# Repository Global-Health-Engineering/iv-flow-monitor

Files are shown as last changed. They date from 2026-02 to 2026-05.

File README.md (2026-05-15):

# Dripito — IV Drip Flow Monitor (Rev-B)

> Improving a low-cost intravenous infusion flow-rate monitoring device
> for paediatric care in humanitarian healthcare settings.
> ETH Zürich, Global Health Engineering — semester project, 2026.

A single-AA-cell IV drip monitor for resource-constrained clinical
environments. Custom STM32G0 PCB, optical dual-beam drop detection,
monochrome graphic LCD, piezo alarm, ASA-printed enclosure with
gear-driven broom-holder chamber clamp.

### → Full project page: **[gluflex.github.io/dripito](https://gluflex.github.io/dripito)**





Interactive dual-beam simulation, clickable PCB architecture, validation results, architecture decisions, assembly guide. This README covers only the essentials for cloning, building, and reproducing.

## At a glance

| | |
|---|---|
| **MCU** | STM32G071C8TX |
| **Hardware** | Rev-B PCB, KiCad 8.x, hand-assembled |
| **Detection** | Dual-beam optical, sphere-model volume calibration |
| **Power** | Single AA Li-ion via FFC, TPS610981 boost converter |
| **Enclosure** | ASA white FDM, sliding-gear chamber holder — Rev-B integrates the assembly for testing; full mechanical rework expected for Rev-C |
| **Validation** | 19 gravimetric-paired bench runs across 3 sessions (5 V_50 calibration + 11 position-drift + 3 raw-waveform-paired), macro-20 drip set; 7 raw-waveform captures total (4 unpaired warm-ups) |
| **BOM** | ~CHF 39, single-qty (see project page) |
| **Submission** | 2026-05-14 |

## Reproduce the analysis

One command, on a clean machine with Docker:

```bash
cd analysis/
docker compose up regenerate-figures-sample   # cold-clone test (sample data)
docker compose up regenerate-figures          # real campaign data
```

Pipeline source: [`analysis/notebooks/validation.ipynb`](analysis/notebooks/validation.ipynb).
Dependencies hash-locked in [`analysis/requirements.txt`](analysis/requirements.txt).
Protocol: [`docs/testing-and-validation.md`](docs/testing-and-validation.md).

## Build the firmware

1. Open `firmware/STM32CubeIDE/Dripito/` in STM32CubeIDE.
2. *Project → Build All*.
3. Connect ST-Link, *Run → Debug*.

Pin maps in [`firmware/README.md`](firmware/README.md).

## Hardware fabrication

PCB from `hardware/gerbers/` (JLCPCB / PCBWay).

Enclosure: STEP and STL exports in [`hardware/3dmodels/Enclosure/`](hardware/3dmodels/Enclosure/) (source CAD in Onshape). The current Rev-B enclosure is **not the final mechanical design** — it integrates the PCB + chamber holder + optics + battery into a testable assembly so the rest of the device can be validated. A full mechanical rework is expected for Rev-C. See [`docs/decisions/chamber-holder-mechanism.md`](docs/decisions/chamber-holder-mechanism.md), [`docs/decisions/sensor-arm-alignment.md`](docs/decisions/sensor-arm-alignment.md), and [`docs/enclosure-requirements.md`](docs/enclosure-requirements.md) for the rationale and Rev-C path.

## Repository layout

```
hardware/        KiCad 8.x project — schematic, PCB, libs, datasheets, gerbers, 3D models (PCB + Enclosure)
firmware/        STM32CubeIDE workspace (Dripito Rev-B)
enclosure/       Rev-B-is-not-final framing + cross-references; CAD lives in hardware/3dmodels/Enclosure/
docs/            Architecture decisions, requirements, results, limitations
data/            Raw validation CSVs, UART logs, gravimetric scale streams, geometry, edge cases
analysis/        Reproducible analysis pipeline (Docker + Jupyter) + diagnostic plotters + figures
tools/           Bench helpers (UART logging, scale logging, position-overlay rendering)
site/            GitHub Pages source (Astro)
media/           Photos, renders, demo clips
HANDOVER.md      State-of-the-prototype handover (Rev-B → Rev-C, what works / blockers / path)
CONTRIBUTING.md  Contribution guidelines (PRs paused during grading)
```

Each folder has its own `README.md`.

For the next person picking this up, start with [`HANDOVER.md`](HANDOVER.md): what works in Rev-B scope, the three blockers (position-dependence, drop-shape oscillation, tilt sensitivity), and the Rev-C optical-front-end path. [`docs/limitations.md`](docs/limitations.md) §17 is the matching architectural finding with bench evidence.

## Citation

A bachelor thesis preceded this work:

> Catarci, L. (2025). *Improving a Low-Cost Intravenous Infusion Flow-Rate Monitoring Device for Paediatric Care in Humanitarian Healthcare Settings*. ETH Zürich, Global Health Engineering. DOI: [10.5281/zenodo.16902366](https://doi.org/10.5281/zenodo.16902366).

The Rev-B work in this repository:

> Catarci, L. (2026). *Dripito — Open-Source IV Drip Flow Monitor (Rev-B)*. ETH Zürich, Global Health Engineering. DOI: [10.5281/zenodo.20199232](https://doi.org/10.5281/zenodo.20199232).

## License

- Code, firmware, docs, data: [CC BY 4.0](LICENSE-CC-BY-4.0.md)
- Hardware (KiCad project, custom symbols, most footprints): [CERN OHL 2.0 Permissive](LICENSE-CERN-OHL-2-PERMISSIVE.md)
- Three specific custom footprints: [CC BY-SA 4.0](LICENSE-CC-BY-SA-4.0.md) — see [`hardware/IV_Flow_Monitor_Footprints.pretty/README.md`](hardware/IV_Flow_Monitor_Footprints.pretty/README.md)
- CubeMX/HAL files retain `Copyright (c) STMicroelectronics` headers.

## Author and supervision

**Leandro Catarci** — MSc Mechanical Engineering, ETH Zürich. Semester project at ETH Global Health Engineering, 2026.

**Jakub Tkaczuk** — Supervisor.
**Prof. Elizabeth Tilley** — Group head, Chair of Global Health Engineering, ETH Zürich.

**Project originator:** Dr. Michelle Niescierenko — Boston Children's Hospital / Harvard Humanitarian Initiative.
**Clinical collaborator:** Dr. Janis Tupesis — University of Wisconsin / WHO Emergency Medical Teams.

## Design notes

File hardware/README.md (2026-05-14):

# hardware/

KiCad 8.x electronic design files for the Dripito monitor PCB —
schematic, board layout, project-local symbol and footprint libraries,
component datasheets, and fabrication outputs.

## Top-level files

| File | Purpose |
|---|---|
| `flow_monitor.kicad_pro` | KiCad project file |
| `flow_monitor.kicad_sch` | Schematic |
| `flow_monitor.kicad_pcb` | Board layout |
| `sym-lib-table` | Registers `lib/IV_Flow_Monitor_Symbols.kicad_sym` |
| `fp-lib-table` | Registers `IV_Flow_Monitor_Footprints.pretty/` |
| `power_analysis.md` | Power-architecture analysis notes |

## Subdirectories

| Folder | Purpose |
|---|---|
| [`lib/`](lib/) | Project-local KiCad symbol libraries |
| [`IV_Flow_Monitor_Footprints.pretty/`](IV_Flow_Monitor_Footprints.pretty/) | Project-local KiCad footprint library |
| [`datasheets/`](datasheets/) | Component datasheets (PDFs) for everything on the BOM |
| [`gerbers/`](gerbers/) | Gerber + drill + pick-and-place fabrication outputs |
| [`3dmodels/`](3dmodels/) | 3D models (component STPs + assembled-board STEP exports) |
| [`scripts/`](scripts/) | Hardware-side automation (logo-to-footprint converter) |

## Gitignored paths

`flow_monitor-backups/` (KiCad timed snapshots), `temp/` (KiCad
scratch), `_autosave-*`, `fp-info-cache`.

## Workflow

- Open and build only via the **KiCad GUI** — no CLI build is configured.
- Hand-edits to `.kicad_sch` / `.kicad_pcb` (e.g. via scripts): always
  reopen in the KiCad GUI before committing — these files are sensitive
  to structural regressions that pass a text diff.
- New / copied symbols must have the project name in their `instances`
  block, or KiCad refuses to load them. Don't use `extends` inheritance
  across hierarchical `lib_symbols` blocks — flatten unit definitions.

## Licensing

- Three custom footprints are CC BY-SA 4.0 (see
  [`../LICENSE-CC-BY-SA-4.0.md`](../LICENSE-CC-BY-SA-4.0.md)):
  `SW_HYP_1TS005F-2500-5001`,
  `USB_C_Receptacle_GCT_USB4105-xx-A_16P_TopMnt_Horizontal`,
  `X_SW_Slide_SPDT_SSK12D07VG5`.
- All other hardware design files are CERN OHL 2.0 Permissive (see
  [`../LICENSE-CERN-OHL-2-PERMISSIVE.md`](../LICENSE-CERN-OHL-2-PERMISSIVE.md)).

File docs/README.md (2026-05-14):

# docs/

Project documentation written for an outside reader. The intent is that
someone who clones this repo cold can rebuild the device, understand why
each design decision was made, and reproduce the validation results
without having access to the author's private notes.

Anything written for personal thinking lives elsewhere (PARA-style notes
outside the repo). Anything that should accompany the artefact lives here.

## Documents in this folder

| File | Purpose |
|---|---|
| [`testing-and-validation.md`](testing-and-validation.md) | Pre-registered validation protocol (EXP-0 → EXP-6). Timestamp = pre-registration evidence. |
| [`results.md`](results.md) | Bench-day results: per-run V_true vs V_LCD, V_CAL_K derivation, residuals. |
| [`limitations.md`](limitations.md) | Honest weaknesses ranked by impact on conclusions; includes §17 position-dependence finding. |
| [`enclosure-requirements.md`](enclosure-requirements.md) | Hand-off spec for follow-up theses iterating on the 3D-printed casing. Numbered REQ-x.y requirements, verification mapping, out-of-scope rationale. |
| [`decisions/`](decisions/) | Architecture Decision Records — see [`decisions/README.md`](decisions/README.md). |
| [`bench/`](bench/) | Bench-day session notes and finding logs. |

## Naming convention

- Lowercase kebab-case (`limitations.md`, not `Limitations.md` or
  `limitations_doc.md`).
- One topic per file. Cross-link with relative paths
  (`../analysis/README.md`).
- Dates in filenames only when the document is genuinely point-in-time
  (e.g. `firmware-audit-2026-04-30.md`); otherwise prefer evergreen names.

## Style

- Write for a reader who doesn't share your context. Spell out acronyms
  on first use.
- Lead with the conclusion, then the reasoning. Bury the lede only in
  the Discussion sections where building suspense serves the reader.
- Embed data tables and Mermaid diagrams inline rather than pointing at
  external files when length permits.
- Each non-trivial claim links to its evidence: a CSV under `data/`,
  a notebook cell under `analysis/`, a commit hash, a datasheet under
  `hardware/datasheets/`.

## Cross-references to other folders

- Validation data and protocol → [`testing-and-validation.md`](testing-and-validation.md) →
  [`../data/`](../data/) (raw CSVs) → [`../analysis/`](../analysis/) (notebook).
- Hardware design rationale → [`decisions/`](decisions/) →
  [`../hardware/flow_monitor.kicad_sch`](../hardware/flow_monitor.kicad_sch).
- Firmware architecture → [`../firmware/README.md`](../firmware/README.md) →
  [`../firmware/STM32CubeIDE/Dripito/Core/`](../firmware/STM32CubeIDE/Dripito/Core/).
- Enclosure fit + Rev-C path → [`enclosure-requirements.md`](enclosure-requirements.md) →
  [`../enclosure/`](../enclosure/) → CAD source in
  [`../hardware/3dmodels/Enclosure/`](../hardware/3dmodels/Enclosure/).

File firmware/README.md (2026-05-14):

# firmware/

Embedded C firmware for the Dripito Rev-B monitor. Single CubeIDE
project at `STM32CubeIDE/Dripito/`, targeting **STM32G071C8TX**.

A Rev-A predecessor (STM32G030C8TX, hardware revision A) lives in the
bachelor-thesis archive on Zenodo
([10.5281/zenodo.16902366](https://doi.org/10.5281/zenodo.16902366));
this repository ships only the active Rev-B firmware.

## Build & flash

CubeIDE GUI only — no CLI build is configured.

1. *File → Import → Existing Projects into Workspace* — point at
   `firmware/STM32CubeIDE/Dripito/`.
2. To regenerate HAL after a peripheral config change, open
   `Dripito.ioc` and click *Generate Code*. Preserve any
   `Copyright (c) STMicroelectronics` headers — they are reapplied on
   regeneration.
3. *Project → Build All*.
4. Connect ST-Link, *Run → Debug*.

## Pin map highlights

| Function | Pin |
|---|---|
| IR detector top / bottom | PA1 / PA4 (`ADC_IR_DETECTOR_TOP/BOT`) |
| LED driver top / bottom | PB3 / PB4 (`LED_CTRL_TOP/BOT`) |
| Battery sense | PB2 (`ADC_V_BAT`) |
| Buzzer PWM | PA8 (`BUZZER_CTRL`) |
| Buttons (MUTE / MODE / RES) | PB6 / PB7 / PB8 |
| UART (debug) | PA9 / PA10 |

Source of truth: `STM32CubeIDE/Dripito/Core/Inc/main.h`.

## CubeIDE pitfalls

- `.metadata/`, `.settings/`, `.cproject`, `.project`, `Debug/`,
  `Release/`, and `*.launch` are machine-specific and gitignored.
- Editing peripheral config without regenerating the `.ioc` will
  silently desync HAL init from the documented configuration.

## License

Generated CubeMX/HAL code retains its `Copyright (c) STMicroelectronics`
headers. Hand-written code in `Core/Src/` is covered by
[`../LICENSE-CC-BY-4.0.md`](../LICENSE-CC-BY-4.0.md).

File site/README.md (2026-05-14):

# Dripito — GitHub Pages site

Astro-based static site for the Dripito open-source IV drip flow monitor. Single landing page composing every section: dual-beam architecture animation, real PCB layout (extracted from the KiCad project), analysis + validation results, architecture decisions, BOM with qty=1 / qty=1000 toggle, limitations, and an assembly walkthrough.

## Local development

```bash
npm install
npm run dev          # http://localhost:4321
npm run build        # static output to dist/
npm run preview      # preview the production build locally
```

## Deploy to GitHub Pages

The [`.github/workflows/deploy-site.yml`](../.github/workflows/deploy-site.yml) workflow builds and deploys on every push to `v2`. GitHub Pages source must be set to **GitHub Actions** in the repository settings.

`astro.config.mjs` sets `site` to the canonical Pages URL and `base` to `/dripito/`.

## Source structure

```
src/
├── layouts/Base.astro            # html/head/body shell, global CSS, OG/Twitter meta
├── pages/index.astro             # landing page — composes the components
├── components/
│   ├── Nav.astro
│   ├── Hero.astro
│   ├── Problem.astro
│   ├── DualBeam.astro            # animated SVG + live readout
│   ├── PCBArchitecture.astro     # real PCB SVG from KiCad + ADR-linked hotspots
│   ├── PowerTree.astro
│   ├── StateMachine.astro
│   ├── Analysis.astro            # bench-overlay error-budget figure
│   ├── Decisions.astro           # ADR card grid
│   ├── BuildItYourself.astro     # BOM table (CSV-driven, qty toggle)
│   ├── Assembly.astro            # step-by-step build cards
│   ├── Limitations.astro         # top-N limitations surface
│   ├── OpenQuestions.astro
│   └── Footer.astro
└── styles/global.css             # design tokens + all section styles
```

## Where the PCB SVG comes from

The PCB diagram in `PCBArchitecture.astro` was generated from the live KiCad project at `hardware/flow_monitor.kicad_pcb` via the `kicad` skill. To regenerate after a layout change:

1. Run the analyser against the `.kicad_pcb` file to emit `pcb_analysis.json`.
2. Run the build script that converts the analysis into the SVG fragment.
3. Paste the SVG into `src/components/PCBArchitecture.astro`.

## BOM data source

`BuildItYourself.astro` reads [`../hardware/bom.csv`](../hardware/bom.csv) at build time and renders it as a 6-column grouped table with a qty=1 / qty=1000 pill toggle and per-group collapse. Editing the CSV is enough to update the rendered table — no component-side changes required.

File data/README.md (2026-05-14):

# data/

All measurement data — raw UART/scale CSVs, per-drop summaries, geometry
measurements, and gravimetric ground-truth — captured during the
2026-05-13 bench campaign. Everything that feeds the analysis pipeline in
`../analysis/` lives here.

## Layout

```
data/
├── raw/                                    # Bench-captured CSVs (see below)
│   ├── 2026-05-13_macro20_50mlh_*          # Morning V_50_01..05 calibration runs
│   ├── 2026-05-13_pm_position_drift/       # Afternoon mount-height re-test (see docs/limitations.md §17)
│   └── 2026-05-14_pm/                      # Trailing bench session
├── sample/                                  # Representative subset for cold-clone reproducibility
├── geometry.json                            # Beam-separation measurement (single board, n=1)
└── gravimetric_log.csv                      # Scale-derived ground truth, per run
```

## File schemas

### `raw/2026-05-13_macro20_50mlh_*` — main calibration set

One run produces up to four files. Filename pattern:

```
2026-05-13_macro20_50mlh_<NN>_board1.csv          # UART event log (RAW/DROP/CAL rows)
2026-05-13_macro20_50mlh_<NN>_board1.log          # Raw UART text capture (audit trail)
2026-05-13_macro20_50mlh_<NN>_board1_perdrop.csv  # Per-drop summary (transit + pulses + volume)
2026-05-13_macro20_50mlh_<NN>_board1_scale.csv    # Gravimetric scale stream (timestamped grams)
```

`<NN>` is the run index (`01`..`05`, plus `_test`, `_03_streaming`, and `_04_aborted` variants).

UART CSV columns:

```
abs_ms, drop_N, transit_us, pulse_top_us, pulse_bot_us,
v_cmps, d_0.1mm, V_0.1uL, state, Q_cmLph, top_raw, bot_raw
```

`_perdrop.csv` is the post-processed condensation produced by
`../analysis/scripts/load_run.py` — one row per detected drop, aligned
to the scale stream:

```
uart_idx, step_idx, t_uart_rel_ms, t_step_rel_ms, t_lag_ms,
delta_g, v_true_uL, v_est_uL, v_diff_uL
```

`_scale.csv` is the scale stream sampled at ~23 Hz:

```
t_ms, mass_g, status
```

### `raw/2026-05-13_pm_position_drift/`

Afternoon mount-height re-test that produced the §17 position-dependence
finding (`docs/limitations.md` §17). Per-run README inside the folder
documents each mount position and the K-value required to make the
LCD-summed drop volume match the gravimetric reading at that position.

### `raw/2026-05-14_pm/`

Trailing bench captures from the day after the main campaign — kept for
provenance; not used in the headline V_50 results.

### `geometry.json`

Single-board beam-separation measurement with caliper repeats. Schema:

```json
{
  "beam_separation_mm":         {"mean": 10.2, "sd": 0.3, "n_boards_measured": 1, "cad_nominal_mm": 10.0},
  "caliper_resolution_mm":      0.05,
  "positioning_uncertainty_mm": 0.5,
  "measured_by":                "digital calipers",
  "measurement_date":           "2026-05-07"
}
```

`n_boards_measured = 1` — board-to-board scatter is un-quantified for
Rev-B and named explicitly in `docs/limitations.md` §8.

### `gravimetric_log.csv`

Per-run summary table. One row per run with:

```
run_id, csv_filename, flow_rate_target_mlh, gravimetric_mass_g,
run_duration_s, drop_count_device, notes
```

`V_true_chamber = gravimetric_mass_g / drop_count_device` (computed in
the analysis notebook) is the per-run chamber-drop ground truth used by
`../analysis/notebooks/validation.ipynb`. The `notes` column records the
firmware-constants context for each run.

## Reproducibility

`sample/` exists so the analysis notebook in `../analysis/` runs
end-to-end even without access to the full dataset. The Docker pipeline
`docker compose up regenerate-figures-sample` uses `sample/` only and is
the path exercised by CI.

The complete dataset will be deposited on Zenodo under CC BY 4.0; DOI
will be added here on mint.

## FAIR principles

- **Findable** — files referenced from this README and the Pages site;
  Zenodo DOI on submission.
- **Accessible** — public GitHub repository, no authentication.
- **Interoperable** — plain CSV with documented column meanings and units;
  JSON for structured metadata.
- **Reusable** — CC BY 4.0; provenance captured in the per-run UART log
  files; per-run gravimetric reference preserved alongside the UART
  streams.

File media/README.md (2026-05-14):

# media/

Photographs, renders, and short demo clips of the Dripito monitor —
the visual material that is embedded in the top-level `README.md`,
`docs/results.md`, and `docs/enclosure.md`, plus any presentation or
publication assets.

## Contents

| File | What it is |
|---|---|
| `pcb.jpg` | Photograph of the assembled PCB |
| `schematic.jpg` | Rendered schematic snapshot |
| `3dmodel_front.jpg` | Front view of the 3D model render |
| `3dmodel_back.jpg` | Back view of the 3D model render |

## Naming convention

- Lowercase kebab-case for stable assets:
  `assembled-device-front.jpg`, `enclosure-cross-section.png`.
- For dated / iteration shots (bench photos, print attempts):
  `YYYY-MM-DD_<short-description>.jpg` — date prefix lets `ls` order
  by capture day naturally.
- Renders include `_render` in the filename so they don't get confused
  with photographs (e.g. `assembled-device-front_render.png`).

## Format and resolution

- Photographs: JPEG, max edge ≤ 2048 px, ~80 % quality. Embed at the
  display size you actually need; do not commit 24 MP originals.
- Renders: PNG when transparency or sharp edges matter (UI mockups,
  schematic renders), JPEG otherwise.
- Animated demos: MP4 (H.264) preferred over GIF for file-size
  reasons. ≤ 5 MB per clip; longer demos go on Zenodo / YouTube and
  are linked from the README.

## What does not belong here

- Slide decks (`.pptx`, `.key`) — those go in
  `../docs/presentations/` if added.
- Photos containing identifiable patient information or clinical
  imagery without consent. None expected.
- Working files (Photoshop `.psd`, source video projects). Commit only
  the exported asset.
- Internal print-history photos for enclosure iterations — drop them next to the matching enclosure ADR / log entry rather than here.

## Embedding from Markdown

From the top-level README (or any sibling-of-`media/` markdown file), reference assets under `media/<filename>`. From a sibling folder (e.g. `docs/`), step up first: `../media/<filename>`. Concrete examples in [`../README.md`](../README.md) and [`../enclosure/README.md`](../enclosure/README.md).

Use relative paths so embedding works on GitHub, locally, and in the
GitHub Pages site.

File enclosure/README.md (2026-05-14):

# enclosure/

> **Current Rev-B enclosure is not the final mechanical design.** A full rework is expected for Rev-C. The Rev-B enclosure exists to integrate the PCB + chamber holder + optics + battery into a single testable assembly so the rest of the device (electronics, firmware, validation campaign) could be exercised. Documented honestly here; planned Rev-C path captured in the cross-referenced ADRs below.

## Where the CAD lives

- **Source CAD:** Onshape document `Dripito Rev-B`. Edits happen there.
- **Versioned exports (STEP + STL):** [`../hardware/3dmodels/Enclosure/`](../hardware/3dmodels/Enclosure/). Populated as the source CAD is exported. The exporter is manual — there is no automation; regenerate after meaningful CAD changes.

This folder (`enclosure/`) carries the rationale, requirements spec, and printing guidance. The geometry itself lives next to the PCB models in `hardware/3dmodels/Enclosure/`.

## Material

ASA white (Acrylonitrile Styrene Acrylate). Decision rationale: [`../docs/decisions/enclosure-material.md`](../docs/decisions/enclosure-material.md). Brief: ASA chosen over PETG (lower UV resistance) and ABS (higher warping risk) for outdoor humanitarian deployment contexts. White colouring reduces solar heat absorption.

## Fastener mechanism

Snap-fit assembly. No heat-set inserts, no threaded fasteners. The trade-off is that snap-fit reliability depends on print tolerance, and disassembly for service requires either flexing the snap-fit lugs or accepting that the enclosure is functionally non-serviceable. See [`../docs/decisions/enclosure-material.md`](../docs/decisions/enclosure-material.md) for the alternative path (M2 brass heat-set inserts + button-head screws) that was rejected for Rev-B.

## Print profile defaults

- Layer height: 0.2 mm (sensor arm: 0.15 mm at optical faces)
- Wall count: 4
- Top/bottom layers: 5
- Infill: 30 % gyroid
- Print orientation: sensor arm prints with the optical bore axis vertical so the LED / PD bores form circular cross sections rather than stair-stepped ellipses
- Support: tree, only where required

ASA process settings (varies by spool): enclosed chamber, ~100 °C bed, ~250 °C nozzle. Calibrate the printer before running the parts.

## Button stack-up

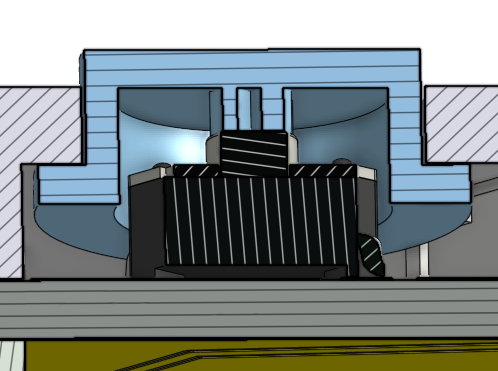
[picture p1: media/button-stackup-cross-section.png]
Button cross-section


Cross-section through a front-plate button. From bottom to top:

- **PCB** (yellow strip)
- **Tactile switch** (PTS647 series, centre — ribbed black SMD body)
- **Front-plate housing** (cross-hatched) with a chamfered bore that captures the cap
- **Button cap** (blue) with a chamfered guide that limits lateral travel

The cap presses the tactile switch directly through the housing bore. No separate light pipe or actuator pin — travel is bounded by the housing chamfer above and the switch dome below.

## Chamber-OD compatibility

Designed for ISO 8536-4-compliant drip chambers, **14–24 mm outer diameter** (microdrip + standard adult macrodrip). Validated against a Ø20 mm reference chamber.

Wide-body / transfusion chambers (25–30 mm) are **out of scope** for Rev-B. Addressable in a future revision via an interchangeable cradle insert reusing the same optical-bay interface. See [`../docs/enclosure-requirements.md`](../docs/enclosure-requirements.md) for the full spec.

## Known limitations of the Rev-B enclosure

The current Rev-B build has known mechanical compromises that were accepted to unblock the validation campaign. These are surfaced in the architecture decision records and in `docs/limitations.md`:

- **Chamber holder geometry** — sliding gear with IR-beam pass-through forces a wide beam-to-sensor distance; partly responsible for the position-dependence finding in [`../docs/limitations.md`](../docs/limitations.md) §Position-dependence. See [`../docs/decisions/chamber-holder-mechanism.md`](../docs/decisions/chamber-holder-mechanism.md).
- **Sensor-arm alignment is FDM-tolerance-bound (±0.2 mm).** Rev-C path is injection moulding (±0.05 mm). See [`../docs/decisions/sensor-arm-alignment.md`](../docs/decisions/sensor-arm-alignment.md).
- **External AA battery holder** acts as counterbalance but increases horizontal footprint, which may interfere with adjacent IV lines in a crowded clinical bay. See [`../docs/decisions/enclosure-geometry.md`](../docs/decisions/enclosure-geometry.md).
- **IP54 ingress protection is an aspiration**, not validated against IEC 60529 in Rev-B. See [`../docs/decisions/enclosure-material.md`](../docs/decisions/enclosure-material.md) §Outlook.

## Cross-references

- Requirements spec for Rev-C / follow-up: [`../docs/enclosure-requirements.md`](../docs/enclosure-requirements.md)
- ADRs governing the enclosure decisions: [`../docs/decisions/enclosure-material.md`](../docs/decisions/enclosure-material.md), [`../docs/decisions/enclosure-geometry.md`](../docs/decisions/enclosure-geometry.md), [`../docs/decisions/chamber-holder-mechanism.md`](../docs/decisions/chamber-holder-mechanism.md), [`../docs/decisions/sensor-arm-alignment.md`](../docs/decisions/sensor-arm-alignment.md)
- Geometry measurement protocol (EXP-1): [`../docs/testing-and-validation.md`](../docs/testing-and-validation.md)
- Geometry data per board: [`../data/geometry.json`](../data/README.md)

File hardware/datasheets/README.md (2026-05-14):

# hardware/datasheets/

PDF datasheets for every component on the Dripito BOM, plus selected
controller datasheets and application notes referenced from the design.

## Naming convention

- `<MPN>_datasheet.pdf` for the primary datasheet of a component
  (`STM32G030C8_datasheet.pdf`, `AO3401A_datasheet.pdf`).
- `<part_or_topic>_<descriptor>.pdf` for application notes, controller
  datasheets, or wiring diagrams (`SSD1803A_controller_datasheet.pdf`,
  `DOG_3V3_wiring.pdf`).

## What's currently here

| File | What it is |
|---|---|
| `STM32G030C8_datasheet.pdf` | Rev-A MCU (kept for reference; Rev-B uses STM32G071C8 — datasheet not duplicated here, see [ST product page](https://www.st.com/en/microcontrollers-microprocessors/stm32g071c8.html)) |
| `TPS610981_datasheet.pdf` | TPS61098-family boost converter — Rev-B uses the TPS610981 variant per the schematic (see [`../../docs/decisions/power-architecture.md`](../../docs/decisions/power-architecture.md)). The PDF is the joint datasheet for the TPS61098, TPS610981, and TPS610982 voltage variants. |
| `AO3401A_datasheet.pdf` | P-channel MOSFET |
| `EA_DOGS164W-A_datasheet.pdf` + `_extended_datasheet.pdf` | LCD module (4×16) |
| `DOG_3V3_wiring.pdf` | LCD wiring reference |
| `SSD1803A_controller_datasheet.pdf` | LCD controller IC; required for the BF-read protocol |
| `PTS647_datasheet.pdf` | Tactile switches (S1 / S2 / S3 buttons) |
| `competitors/` | Reference material for prior-art devices (DripAssist) |

## What does **not** belong here

- Product brochures and marketing PDFs that aren't actual technical references.
- Datasheets for components considered but rejected — those belong in
  the relevant decision record, not here.

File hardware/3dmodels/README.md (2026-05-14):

# hardware/3dmodels/

3D models for component visualisation in the KiCad PCB editor, the
exported board `.step`, and the mechanical enclosure exports. Organised
into subfolders by what each model represents.

## Layout

```
hardware/3dmodels/
├── PCB/              # Board + on-PCB component models
│   ├── PTS647SN38SMTR2_LFS.stp
│   ├── flow_monitor.step
│   └── flow_monitor_full.step
└── Enclosure/        # Mechanical enclosure exports from Onshape (STEP + STL)
                      # (populated as the source CAD is exported)
```

## PCB models

| File | What it is |
|---|---|
| `PCB/PTS647SN38SMTR2_LFS.stp` | 3D model for the PTS647 tactile switch |
| `PCB/flow_monitor.step` | Assembled-board STEP export from KiCad (board only) |
| `PCB/flow_monitor_full.step` | Assembled-board STEP export including 3D component models |

Conventions for PCB models:

- One file per component, named after the part's MPN: `<MPN>.stp` or `<MPN>.wrl`.
- STEP (`.stp` / `.step`) preferred over VRML (`.wrl`) — STEP preserves geometry for the assembled board export.
- Models come from manufacturer or distributor websites (DigiKey / Mouser / vendor 3D-model download links). Note provenance in the BOM entry.

## Enclosure models

Source CAD lives in Onshape (`Dripito Rev-B`). STEP and STL exports land in `Enclosure/` for version-controlled distribution to slicers and downstream consumers.

The current Rev-B enclosure is **not the final mechanical design**. It exists to integrate the PCB + chamber holder + optics + battery into a testable assembly so the rest of the device can be validated. A full rework is expected for Rev-C — see [`../../docs/decisions/chamber-holder-mechanism.md`](../../docs/decisions/chamber-holder-mechanism.md), [`../../docs/decisions/sensor-arm-alignment.md`](../../docs/decisions/sensor-arm-alignment.md), and [`../../docs/decisions/enclosure-material.md`](../../docs/decisions/enclosure-material.md) for the rationale and Rev-C path.

## Stray folders

`Neuer Ordner/` is a third-party download artefact, gitignored — not part of this project.

## License caveat

Manufacturer 3D models often carry redistribution restrictions. Most explicitly permit inclusion in derivative PCB designs and assembled mechanical models, but not standalone redistribution. If you are republishing this repo separately, audit each `.stp` against its source license terms. For models with unclear licensing, replace them with a generic shape or omit and accept the cosmetic loss in the `.step` export.

## Linking from a footprint

In the KiCad Footprint Editor:

1. *Properties → 3D Models → Add*.
2. Use a relative path: `${KIPRJMOD}/3dmodels/PCB/<MPN>.stp` so the link travels with the project.
3. Save the footprint. The board's `.step` export now picks up the model automatically.

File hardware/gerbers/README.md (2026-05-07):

# hardware/gerbers/

Fabrication outputs for the Dripito Rev-B PCB: Gerber files (one per
copper / mask / silk / paste / outline layer), drill files (PTH and
NPTH), pick-and-place files, the bundled `.zip` for fab-house upload,
and the `.gbrjob` job description.

These files are **regenerated** from `../flow_monitor.kicad_pcb` — the
`.kicad_pcb` is the source of truth. Treat the Gerbers as build
artefacts that happen to be committed for traceability.

## What's here

| File | Layer / role |
|---|---|
| `flow_monitor-F_Cu.gtl` / `-B_Cu.gbl` | Front / back copper |
| `flow_monitor-F_Mask.gts` / `-B_Mask.gbs` | Front / back solder mask |
| `flow_monitor-F_Silkscreen.gto` / `-B_Silkscreen.gbo` | Front / back silkscreen |
| `flow_monitor-F_Paste.gtp` / `-B_Paste.gbp` | Front / back paste mask |
| `flow_monitor-Edge_Cuts.gm1` | Board outline |
| `flow_monitor-PTH.drl` / `-NPTH.drl` | Plated / non-plated drill |
| `flow_monitor-top.pos` / `-bottom.pos` | Pick-and-place coordinates |
| `flow_monitor-job.gbrjob` | Job description (Gerber X3) |
| `flow_monitor.csv` | Component-position CSV (assembly) |
| `flow_monitor_gerbers.zip` | Bundled archive for fab-house upload |
| `placement/` | Auxiliary pick-and-place outputs |

## Re-exporting

After a layout change, regenerate via KiCad → *File → Fabrication
Outputs* (Gerbers, Drill Files, Component Placement). Re-zip
`flow_monitor_gerbers.zip` from the freshly generated files. Commit
with a message that names the source PCB commit:
`refactor(hardware): regenerate gerbers after <change>`.

## Fab-house

Default target: JLCPCB. 2-layer, 1.6 mm, ENIG or HASL. The same
Gerber + drill bundle works for PCBWay; pick-and-place CSV format may
need a per-fab conversion.

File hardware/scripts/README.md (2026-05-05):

# hardware/scripts/

Hardware-side automation. Currently a single script for converting
PNG / JPG logos into KiCad silkscreen footprints, plus the source
artwork it consumes.

## Contents

| File | Purpose |
|---|---|
| `logo_to_footprint.py` | Rasterises a logo image into a KiCad `.kicad_mod` footprint on F.SilkS, using `fp_poly` rectangles. Enforces the ≥ 0.2 mm minimum feature size required by JLCPCB silkscreen. Uses PIL + numpy. |
| `eth_logo.png` | ETH Zürich logo source artwork |
| `ghe_logo.jpg` | Global Health Engineering logo source artwork |

## Usage

```bash
cd hardware/scripts
python logo_to_footprint.py --input eth_logo.png \
                            --output ../IV_Flow_Monitor_Footprints.pretty/ETH_Zurich_Logo.kicad_mod \
                            --pixel-size 0.2
```

(Exact CLI may vary — read the script for the argument set it
actually accepts.)

The output footprints live in `../IV_Flow_Monitor_Footprints.pretty/`.
Regenerate them rather than hand-editing if the source artwork
changes; the script enforces silkscreen design rules so manual
editing risks producing non-fab-able geometry.

## Conventions

- Python 3 with `pillow` (PIL) and `numpy` as the only non-stdlib
  dependencies. Keep this folder dependency-light — install via system
  Python or a one-off venv; do not introduce a `requirements.txt` here
  (the analysis pipeline's pinning lives at `../../analysis/` instead).
- One script per task. If a second tool is added (e.g. a BOM diff
  helper), it gets its own file rather than expanding `logo_to_footprint.py`.
- Output destinations are passed as CLI arguments, not hard-coded —
  each script must run cleanly from the repo root or from inside this
  folder.

## What does not belong here

- Firmware build / flash scripts (those would go under
  `../../firmware/scripts/` if added).
- Analysis-pipeline code (lives at `../../analysis/scripts/`).
- Bytecode / `__pycache__/` (gitignored).

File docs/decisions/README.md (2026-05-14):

# docs/decisions/ — Architecture Decision Records

One file per significant architectural or engineering decision. The point
is that a reader can reconstruct *why* the design looks the way it does
without asking the author. Each decision page is a contract with the
future: what was decided, what alternatives were rejected, what would
trigger a revisit.

## File format

Each decision is a single Markdown file with a stable structure:

```markdown
# <Decision title>

**Date:** YYYY-MM-DD

## Context
What problem does this solve? What constraints apply? What did we know
that the reader doesn't?

## Decision
The chosen option, stated unambiguously. One sentence if possible.

## Alternatives considered
Each alternative + why it lost. Cost, risk, complexity, supplier
availability — be concrete.

## Consequences
What this decision unlocks. What it forecloses. What we now have to live
with that we didn't before.

## Revisit triggers
Conditions under which this decision should be re-opened (e.g.
"if Rev-C uses a Li-ion cell, revisit boost converter selection").
```

## Naming convention

- Lowercase kebab-case, action-or-noun phrase: `comparator-simplification.md`,
  `power-architecture.md`, `auto-calibration-at-boot.md`.
- No dates in filename (the date is inside the file, in the frontmatter
  block above). Files are evergreen even after they're superseded.
- A superseded decision **stays in the repo** with `Status: superseded by
  [link]`. Deleting it loses the reasoning trail.

## Decision records in this folder

| File | Topic |
|---|---|
| [`comparator-simplification.md`](comparator-simplification.md) | COMP1 → internal-comparator simplification (remove LMV331) |
| [`optical-architecture.md`](optical-architecture.md) | Dual-beam Phase 1 / LPTIM Phase 2 trade-off |
| [`power-architecture.md`](power-architecture.md) | Single Li-ion AA via TPS610981 boost |
| [`power-architecture-process.md`](power-architecture-process.md) | Companion record: how the power decision was made (supervisor pushback, Tupesis consultation, solar feasibility) |
| [`enclosure-material.md`](enclosure-material.md) | ASA white, FDM, snap-fit |
| [`enclosure-geometry.md`](enclosure-geometry.md) | External AA holder on sensor arm as counterbalance |
| [`sensor-arm-alignment.md`](sensor-arm-alignment.md) | FDM in Rev-B; injection moulding pathway for Rev-C |
| [`chamber-holder-mechanism.md`](chamber-holder-mechanism.md) | Sliding gear with IR-beam pass-through (Rev-C rework expected) |
| [`usb-interface-removal.md`](usb-interface-removal.md) | USB-C dropped; 5-pin UART debug header instead |
| [`battery-cell-size.md`](battery-cell-size.md) | AA retained vs AAA (DripAssist battery-life benchmark) |
| [`care-package-deployment.md`](care-package-deployment.md) | Planned deployment kit (3–5 units + alkaline AA fallback + external USB solar panel); not executed in Rev-B |
| [`battery-indicator.md`](battery-indicator.md) | Low-battery symbol via threshold (deferred to Rev-C) |
| [`led-duty-cycle.md`](led-duty-cycle.md) | Phase 2 IR LED at 0.3 % duty cycle |
| [`auto-calibration-at-boot.md`](auto-calibration-at-boot.md) | Threshold auto-calibration (primary, no fallback) |
| [`onshape-mcp-evaluation.md`](onshape-mcp-evaluation.md) | Parametric CAD tooling — evaluated, deferred to Rev-C |
| [`firmware-build-and-test-rev-c.md`](firmware-build-and-test-rev-c.md) | CubeIDE-only Rev-B firmware build; Dockerized build + host-side state-machine tests deferred to Rev-C |

## Why ADRs

A code review or supervisor reading the repo cold cannot see the
discussions, dead ends, and stakeholder pushback that shaped the design.
The ADR format makes that history explicit and durable. It captures
tacit engineering judgement as documented rationale a future
contributor or reviewer can audit.

Reference: Michael Nygard, "Documenting Architecture Decisions" (2011),
the canonical ADR pattern.

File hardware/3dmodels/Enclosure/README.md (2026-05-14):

# hardware/3dmodels/Enclosure/

Rev-B enclosure exports from the Onshape `Dripito Rev-B` assembly. The folder splits into the
printable subset (`STL/`) and the full parametric source (`STEP/`).

> The current Rev-B enclosure is **not the final mechanical design** —
> see [`../../../enclosure/README.md`](../../../enclosure/README.md) and
> [`../../../docs/decisions/chamber-holder-mechanism.md`](../../../docs/decisions/chamber-holder-mechanism.md).
> A full mechanical rework is expected for Rev-C.

## Layout

```
Enclosure/
├── STEP/   # Full Onshape assembly — 3 printable parts + 5 component reference models
└── STL/    # Rev-B printable subset — 3 parts only (slicer-ready meshes)
```

The STEPs are the authoritative geometry source from Onshape and include the full assembly
(printable parts plus reference geometry for off-the-shelf components used for clearance and
fit checks). The STLs in `STL/` are the printable subset actually fed into the slicer for the
Rev-B build.

## Printable parts (in `STL/` and `STEP/`)

| File | What it is |
|---|---|
| `Front_Case` | Front-plate housing — LCD window, button cutouts, LED bezel holes |
| `Back_Casing` | Rear shell of the device body |
| `Gear` | Sliding-gear chamber holder with the IR-beam pass-through hole (see [`../../../docs/decisions/chamber-holder-mechanism.md`](../../../docs/decisions/chamber-holder-mechanism.md)) |

All three print in ASA white per [`../../../docs/decisions/enclosure-material.md`](../../../docs/decisions/enclosure-material.md). Print profile defaults: 0.2 mm layer (sensor-arm optical faces at 0.15 mm), 4-perimeter walls, 30 % gyroid infill, tree supports where required.

## Component reference models (in `STEP/` only — not printed)

| File | What it is |
|---|---|
| `AA_Battery` | AA Li-ion cell — clearance / fit reference |
| `body`, `lock`, `pins` | FFC connector sub-bodies (housing, actuator, contact pins) — clearance reference for the on-PCB FFC connector |
| `slide_switch` | SK-12D07-G slide switch — off-board mode/power switch reference |

These remain in `STEP/` for assembly-level fit-checks. They are deliberately omitted from
`STL/` because they are off-the-shelf components, not printable.

## Source

Onshape document `Dripito Rev-B`. The exporter is manual — regenerate STEPs from Onshape after
meaningful CAD changes; export only the printable subset to `STL/`.

## Printing

For a one-shot Rev-B prototype, feed the three STLs in `STL/` (`Front_Case`, `Back_Casing`,
`Gear`) into a slicer (PrusaSlicer / OrcaSlicer / Bambu Studio) configured for ASA per the
print profile defaults above.

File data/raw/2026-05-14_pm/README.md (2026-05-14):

# 2026-05-14 PM — raw beam waveform capture across mount positions

First Dripito bench session to capture the **raw photodiode waveforms** (not just edge-time pulse durations) across mount positions where K-fit broke yesterday. The new dimension this dataset adds is shape information — rise/fall asymmetry, multi-peak structure, area-under-attenuation, umbilical/splash signatures — that the threshold-time analysis used through 2026-05-13 cannot access. Captures support the Phase 2 offline algorithm exploration in `analysis/scripts/algo_replay.py`, `analysis/scripts/algo_breadth_pass.py`, and `analysis/scripts/fit_final_algorithm.py`.

Firmware: `feat/raw-capture-rev-c` (branched from `v2`, not merged into Rev-B submission firmware — submission firmware = `v2` HEAD). Adds compile-time `ENABLE_RAW_CAPTURE=1`, sample-time `ADC_SAMPLETIME_160CYCLES_5` (160.5 cycles; an earlier 3.5-cycle attempt was reverted when the photodiode TIA didn't settle and runtime reads dropped ~10 % below boot-cal), polled register-level pair-read, 8 kB ring buffer (1024 × 8 B), 921600 baud UART (the 2 Mbps plan was reverted with the buffer halving), per-drop CSV dump on accept.

UART format addition (the rest of the schema is unchanged from `docs/results.md` references):

```
DROP_RAW_BEGIN,<t_ms>,<drop_N>,<sample_count>,<t_first_us>,<t_last_us>,<t_trigger_us>
RAW,<t_us>,<top_adc>,<bot_adc>        × sample_count rows
DROP_RAW_END,<drop_N>
```

`t_us` is the free-running TIM2 µs counter (1 MHz, 32-bit wrap-safe). `t_trigger_us` is the t_us at the TOP-entry (tT_in) edge.

## Captures

All captures at the same drip set (macro 20 gtt/mL), water, board 1, flow ≈ 50 mL/h via roller-clamp setting. Position is measured relative to the V_50_05-era canonical mount (the same mount used during the morning calibration campaign).

| Tag | Position | Has scale.csv | Role |
|---|---|---|---|
| `p1_high_capture.log` | canonical V_50_05-era| no | First-light raw-byte capture (pre-format)  |
| `p1_high_first_capture.uart.log` | canonical | no | Initial UART format-validation probe |
| `p1_high_run01.uart.log` | canonical | no | Warm-up run |
| `p1_high_run02.uart.log` | canonical | **yes** | Gravimetric-paired primary at p1 |
| `p2_minus1mm_run01.uart.log` | 1 mm below canonical | no | Warm-up after remount |
| `p2_minus1mm_run02.uart.log` | 1 mm below canonical | **yes** | Gravimetric-paired primary at p2 |
| `p3_minus4mm_run01.uart.log` | 4 mm below canonical | **yes** | Gravimetric-paired (only run at p3) |

The three `*_run02.uart.log` and the `p3_*_run01.uart.log` are the algorithm-evaluation set; the `*_first_*` / `*_run01` captures at p1 and p2 are warm-ups and exist to confirm steady-state behaviour before paired-with-scale acquisition began.

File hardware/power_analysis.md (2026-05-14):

# IV Drip Monitor Power Supply Comparison

## Device Context

- **MCU:** STM32G030C8Tx
- **Target rail:** 3.3V
- **Current PCB:** KiCad design by Smith (2026), uses BQ25185DLHR + TPS631000 buck-boost + 18650 cell
- **Power data sources:** Catarci (2025) Table 3.1, Smith (2026) Table 2.1, component datasheets

---

## Scenario Definitions

| | A: Li-ion AA (USB-C in battery) | B: LiPo Pouch Cell | C: 18650 Cylindrical |
|---|---|---|---|
| **Battery** | [XTAR 4100 mWh USB-C](https://www.xtar.cc/product/xtar-aa-lithium-4100mwh-2450mah-usb-c-battery-with-low-voltage-indicator.html) or [Paleblue 2550 mWh](https://paleblueearth.com/pages/tech-specs) | 1000 mAh / 3.7V pouch cell with NTC | [Samsung 30Q 3000 mAh](https://www.18650batterystore.com/products/samsung-30q) or [Panasonic NCR18650B 3350 mAh](https://www.batteryspace.com/prod-specs/ncr18650b.pdf) |
| **Converter** | Step-up (boost) 1.5V -> 3.3V | Buck-boost 3.0-4.2V -> 3.3V | Buck-boost 3.0-4.2V -> 3.3V |
| **Charging** | Built into battery (USB-C on battery) | USB-C port on device, [BQ25185DLHR](https://www.ti.com/lit/ds/symlink/bq25185.pdf) | USB-C port on device, [BQ25185DLHR](https://www.ti.com/lit/ds/symlink/bq25185.pdf) |
| **Fallback** | Alkaline AA (universal availability) | None (proprietary form factor) | None (but widely sourced in Africa) |

---

## Main Comparison Table

### 1. Battery Capacity

| Metric | A: Li-ion AA | B: LiPo Pouch | C: 18650 |
|---|---|---|---|
| Nominal voltage | 1.5V output (3.7V internal cell with buck regulator) | 3.7V | 3.6-3.7V |
| Capacity (mAh at nominal V) | Paleblue: 1700 mAh / XTAR USB-C: 2450 mAh | 1000 mAh (typical for this size class) | 3000-3350 mAh |
| Energy (mWh) | Paleblue: 2550 / XTAR: 4100 | 3700 | 10,800-12,060 |
| **Usable energy at 3.3V rail (mWh)** | **Paleblue: 2372 / XTAR: 3813** (x0.93 boost eff.) | **3330** (x0.90 buck-boost eff.) | **9720-10,854** (x0.90 buck-boost eff.) |

Sources: [Paleblue tech specs](https://paleblueearth.com/pages/tech-specs); [XTAR AA 4100 mWh USB-C](https://www.xtar.cc/product/xtar-aa-lithium-4100mwh-2450mah-usb-c-battery-with-low-voltage-indicator.html); [Panasonic NCR18650B datasheet](https://www.batteryspace.com/prod-specs/ncr18650b.pdf); [Samsung INR18650-30Q datasheet](https://www.18650batterystore.com/products/samsung-30q). Boost efficiency from [TPS610981 datasheet](https://www.ti.com/lit/ds/symlink/tps61098.pdf) (0.93 at low/medium load). Buck-boost efficiency from [TPS631000 datasheet](https://www.ti.com/lit/ds/symlink/tps631000.pdf) (>0.90 at moderate loads).

### 2. Price of Batteries and ICs

| Component | A: Li-ion AA | B: LiPo Pouch | C: 18650 |
|---|---|---|---|
| **Battery (single unit)** | Paleblue: ~$7.50 / XTAR USB-C: ~$6.75 | $0.80-$1.50 (1000+ qty, with NTC) | $1.50-$2.50 (1000+ qty) |
| **Battery (bulk 1000+)** | ~$5.00-$6.00 (estimated, limited bulk channels) | **$0.80-$1.50** | **$1.50-$2.50** |
| **DC-DC converter IC** | [TPS610981](https://www.ti.com/lit/ds/symlink/tps61098.pdf): ~$1.60 (DigiKey, not on LCSC) / [HT7733A](https://www.lcsc.com/product-detail/C131130.html): **$0.10** (LCSC C131130) | [TPS631000DRLR](https://www.lcsc.com/product-detail/C5219190.html): **$0.26** (LCSC C5219190) | [TPS631000DRLR](https://www.lcsc.com/product-detail/C5219190.html): **$0.26** (LCSC C5219190) |
| **Battery management IC** | Not needed (charger in battery) | [BQ25185DLHR](https://www.lcsc.com/product-detail/Battery-Management_Texas-Instruments-BQ25185DLHR_C19725033.html): **$0.89** (LCSC C19725033) | [BQ25185DLHR](https://www.lcsc.com/product-detail/Battery-Management_Texas-Instruments-BQ25185DLHR_C19725033.html): **$0.89** (LCSC C19725033) |
| **USB-C connector** | Not needed on device | ~$0.20-$0.50 (GCT USB4105) | ~$0.20-$0.50 (GCT USB4105) |
| **Total IC + battery cost** | **$5.10-$8.35** (HT7733A) or **$6.60-$9.85** (TPS610981) | **$2.15-$3.15** | **$2.85-$4.15** |

Sources: [LCSC HT7733A (C131130)](https://www.lcsc.com/product-detail/C131130.html); [LCSC TPS631000DRLR (C5219190)](https://www.lcsc.com/product-detail/C5219190.html); [LCSC BQ25185DLHR (C19725033)](https://www.lcsc.com/product-detail/Battery-Management_Texas-Instruments-BQ25185DLHR_C19725033.html); [TPS610981 datasheet](https://www.ti.com/lit/ds/symlink/tps61098.pdf); [Samsung 30Q retail pricing](https://www.18650batterystore.com/products/samsung-30q).

### 3. Energy Density

| Metric | A: Li-ion AA | B: LiPo Pouch | C: 18650 |
|---|---|---|---|
| **Gravimetric (Wh/kg)** | 137 (Paleblue) - 174 (XTAR 3300 mWh) | ~185 | 200-243 ([Panasonic NCR18650B](https://www.batteryspace.com/prod-specs/ncr18650b.pdf): 243) |
| **Volumetric (Wh/L)** | 304 (Paleblue) - 394 (XTAR) | ~500 | 500-676 (Panasonic NCR18650B: 676) |

Note: Li-ion AA energy density is penalised by the internal buck converter PCB occupying volume and adding weight. The 18650 format achieves the highest energy density due to manufacturing maturity and optimised jelly-roll packing.

Sources: Calculated from cell mass/volume and rated capacity. Paleblue: 2.55 Wh / 18.6 g ([Paleblue tech specs](https://paleblueearth.com/pages/tech-specs)); XTAR: 3.3 Wh / 19 g ([XTAR 3300 mWh](https://xtardirect.com/products/xtar-aa-15v-2000mah-li-ion-battery)); Panasonic NCR18650B: 12.06 Wh / 49.5 g / 17.84 mL ([datasheet](https://www.batteryspace.com/prod-specs/ncr18650b.pdf)). Independent XTAR teardown and efficiency data from [Gough's Tech Zone](https://goughlui.com/2024/08/28/mega-review-xtar-4150mwh-2500mah-1-5v-rechargeable-li-ion-aa-battery-l4-usb-c-charger/).

### 4. Device Running Time on a Single Charge

> **Note on Rev-B scope.** The numbers in this section are the Phase-1 (worst case)
> and Phase-2 (best case) projections from the underlying thesis power model. **Rev-B
> ships in Phase 1 only** — both IR LEDs always-on continuous, no LPTIM duty-cycling
> (see `site/src/components/PCBArchitecture.astro` Hotspot 3 and
> `docs/decisions/led-duty-cycle.md`). The Phase-2 ~30-day runtime is therefore a
> Rev-C deliverable, not a Rev-B claim. The Phase-1 worst-case ~2.5 day runtime is
> the operative number for the as-shipped Rev-B firmware.

Runtime estimated using power consumption data from both theses:
- **Best case** (Catarci, Thesis 1; Phase 2 — Rev-C target): duty-cycled LED (150 us pulses, 8.3% duty) + MCU Stop mode = **1.57 mA** avg at 3.3V = 5.18 mW
- **Worst case** (Catarci, Thesis 1; Phase 1 — Rev-B as shipped): continuous LED operation = **19.5 mA** avg at 3.3V = 64.35 mW
- For scenarios B and C, BQ25185 quiescent current (~150 uA at 3.7V = 0.56 mW) is added

| Runtime | A: Li-ion AA (XTAR 4100 mWh) | A: Li-ion AA (Paleblue 2550 mWh) | B: LiPo Pouch (1000 mAh) | C: 18650 (3000 mAh) | C: 18650 (3350 mAh) |
|---|---|---|---|---|---|
| **Best case** | **30.7 days** (736 h) | **19.1 days** (457 h) | **24.4 days** (586 h) | **71.3 days** (1712 h) | **79.6 days** (1911 h) |
| **Worst case** | **2.5 days** (59 h) | **1.5 days** (37 h) | **2.1 days** (51 h) | **6.3 days** (150 h) | **7.0 days** (168 h) |
| **Alkaline AA fallback** | Best: 22.4 days / Worst: 1.8 days (3000 mWh, matches Thesis 1: 18.6-21 days / 36-40 h) | -- | -- | -- | -- |

Calculation method: Usable_energy_at_3.3V / system_power. For A: E_usable = E_battery x eta_boost (0.93). For B/C: E_usable = E_battery; total_power = (system_power / eta_buckboost) + P_BQ25185_quiescent.

Sources: Catarci (2025) Table 3.1, Appendix C (thesis_1.pdf in this repository); [TPS610981 datasheet](https://www.ti.com/lit/ds/symlink/tps61098.pdf) efficiency curves; [TPS631000 datasheet](https://www.ti.com/lit/ds/symlink/tps631000.pdf); [BQ25185 datasheet](https://www.ti.com/lit/ds/symlink/bq25185.pdf) quiescent current.

### 5. Battery Availability in Africa

Searched across 14 representative countries: Nigeria, Ghana, Senegal, Kenya, Tanzania, Ethiopia, Uganda, South Africa, Mozambique, Malawi, DRC, Cameroon, Egypt, Morocco.

| Country / Region | A: Li-ion AA (USB-C type) | B: LiPo Pouch | C: 18650 | Alkaline AA (fallback for A) |
|---|---|---|---|---|
| **Nigeria** | Not available | Minimal (Jumia, RC hobby only) | Excellent ([Jumia Nigeria](https://www.jumia.com.ng/mlp-18650-battery/), Konga) | Excellent (all platforms + retail) |
| **Ghana** | Not available | Not available | Good ([Jumia Ghana](https://www.jumia.com.gh/mlp-18650-battery/)) | Excellent |
| **Senegal** | Not available | Not available | Likely ([Jumia Senegal](https://www.jumia.sn/mlp-batterie-rechargeable/)) | Good (Jumia, retail) |
| **Kenya** | Partial (XTAR via whizz.co.ke) | Yes, specialty ([Nerokas](https://store.nerokas.co.ke/)) | Excellent ([Jumia Kenya](https://www.jumia.co.ke/mlp-18650-rechargeable-battery/), Kilimall) | Excellent |
| **Tanzania** | Not available | Not available | Limited (Jiji, Shopit, Kariakoo market) | Good (physical retail) |
| **Ethiopia** | Not available | Not available | Limited (Jiji, Merkato market) | Good (physical retail) |
| **Uganda** | Not available | Not available | Good ([Jumia Uganda](https://www.jumia.ug/mlp-18650-battery/)) | Good (Jumia, retail) |
| **South Africa** | **Yes** ([Takealot](https://www.takealot.com/): EBL, BESTON, EnerC) | Yes, specialty ([DIY Electronics](https://www.diyelectronics.co.za/store/152-li-ion-li-po)) | Excellent ([Takealot](https://www.takealot.com/computers/general-purpose-batteries-29176)) | Excellent |
| **Mozambique** | Not available | Not available | Uncertain (source from South Africa) | Limited (physical retail) |
| **Malawi** | Not available | Not available | Uncertain (Ubuy, PowerTex) | Limited (physical retail) |
| **DRC** | Not available | Not available | Uncertain (physical markets Kinshasa) | Limited (physical retail) |
| **Cameroon** | Not available | Not available | Likely (E-Tech Store, Ubuy) | Available (retail) |
| **Egypt** | Not available | Yes, specialty ([Micro Ohm](https://microohm-eg.com/batteries-chargers-holders/batteries/micro-lipo-batteries/)) | Excellent ([Jumia Egypt](https://www.jumia.com.eg/mlp-18650-battery/), [Noon](https://www.noon.com/egypt-en/), [Amazon.eg](https://www.amazon.eg/)) | Excellent |
| **Morocco** | Not available | Not available | Good ([Jumia Morocco](https://www.jumia.ma/mlp-batterie-18650/)) | Good (Jumia) |
| **Availability score** | **1/14 countries** (SA only confirmed) | **3/14 countries** (specialty stores) | **10+/14 countries** | **14/14 countries** |

**Alkaline AA fallback assessment for Scenario A:** Alkaline AAs are universally available across all 14 surveyed countries, from e-commerce platforms (Jumia, Takealot, Noon) to corner shops, gas stations, and street vendors. Brands include Duracell, Energizer, Panasonic, GP, and local alternatives. This makes the alkaline AA fallback highly realistic. However, alkaline cells are non-rechargeable and provide ~22 days (best) to ~1.8 days (worst) per cell, creating ongoing consumable costs (CHF 0.20/cell x ~17-200 cells/year depending on duty cycle).

**Replacement options in case of complete battery failure:**

| Scenario | Replacement Strategy |
|---|---|
| A (Li-ion AA fails) | Replace with alkaline AA from any local shop. Loss of rechargeability. NiMH AA with external charger also available in most markets. |
| B (LiPo pouch fails) | Must source from specialty electronics retailer (South Africa, Kenya, Egypt only) or import. Device is non-functional until replacement arrives. |
| C (18650 fails) | Replace from local market in most African cities. Flashlight/solar/vape shops commonly stock 18650 cells. |

Note: Jumia, Takealot, and similar African e-commerce platforms block automated URL verification (HTTP 403), but all listed store URLs were confirmed via manual research by the search agents. Paleblue does not ship internationally outside US/EU; Amazon prohibits international shipping of lithium batteries as hazmat.

### 6. Swelling Risk

| Factor | A: Li-ion AA | B: LiPo Pouch | C: 18650 |
|---|---|---|---|
| **Casing type** | Rigid metal cylindrical can | Soft aluminum laminate | Rigid steel cylindrical can |
| **Swelling risk level** | **Low** | **High** | **Very low** |
| **Dimensional change over life** | Negligible externally | 8-10% thickness increase over 500 cycles; up to 32% in aggressive conditions | Negligible externally |
| **Safety mechanisms** | Internal protection PCB (overcharge, over-discharge, short-circuit, thermal cutoff) | Relies on thermal seal as rupture point; no CID or vent | CID at 1.06-1.29 MPa + burst disc vent at 2.2-2.3 MPa + PTC |
| **Design implication** | No special clearance needed | Must design 10-15% clearance in enclosure for swelling | No special clearance needed |

Sources: [MDPI Batteries 8(5):42 -- pouch cell expansion](https://doi.org/10.3390/batteries8050042); [Frontiers in Chemical Engineering -- gas generation in pouch cells](https://www.frontiersin.org/journals/chemical-engineering/articles/10.3389/fceng.2022.828375/full); [NASA 18650 safety analysis (NTRS)](https://ntrs.nasa.gov/api/citations/20100037250/downloads/20100037250.pdf).

### 7. Self-Discharge Rate When Not in Use

| Condition | A: Li-ion AA | B: LiPo Pouch | C: 18650 |
|---|---|---|---|
| **At 25 C** | **5-8%/month** (electrochemical 1-2% + internal buck regulator quiescent ~20-30 uA continuously) | **3-5%/month** | **1-3%/month** |
| **At 35 C** | 9-14%/month | 5-9%/month | 2-5%/month |
| **At 45 C** | 15-24%/month | 9-15%/month | 3-9%/month |
| **Months to 50% capacity loss at 25 C** | ~7-10 months | ~10-17 months | ~17-50 months |
| **Critical note** | Internal buck converter draws quiescent current even when device is off; **worst shelf life** | Moderate | **Best shelf life**; no parasitic electronics drain in bare cell |

Sources: [Battery University BU-802b](https://www.batteryuniversity.com/article/bu-802b-what-does-elevated-self-discharge-do); [Gough's Tech Zone XTAR teardown](https://goughlui.com/2024/08/28/mega-review-xtar-4150mwh-2500mah-1-5v-rechargeable-li-ion-aa-battery-l4-usb-c-charger/) (buck converter efficiency and quiescent current data); Arrhenius self-discharge model Ea ~ 0.94 +/- 0.14 eV, Q10 ~ 1.5-2.0x per [Schindler et al., J. Power Sources (2023)](https://doi.org/10.1016/j.jpowsour.2022.232309).

### 8. Number of Charge/Discharge Cycles

| Condition | A: Li-ion AA | B: LiPo Pouch | C: 18650 |
|---|---|---|---|
| **Manufacturer-rated (to 80% capacity)** | Paleblue: **1000+** / XTAR: **1000-1200** | **500+** (at 0.2C, 100% DoD) | **300-500** (at 100% DoD) |
| **At 80% DoD** | ~1000-1200 | ~500-800 | ~500+ |
| **At 40% DoD (shallow cycling)** | Not published | ~800-1200 | ~1250 |
| **At 20% DoD** | Not published | Not published | ~2500 |

Note: Li-ion AA cells achieve higher cycle counts because the internal protection circuitry prevents deep discharge and overcharge abuse. For scenarios B and C, the [BQ25185](https://www.ti.com/lit/ds/symlink/bq25185.pdf) provides similar protection (+/-0.5% charge voltage accuracy), which improves real-world cycle life over the datasheet minimum.

Sources: [Paleblue tech specs](https://paleblueearth.com/pages/tech-specs); [XTAR 3300 mWh specs](https://xtardirect.com/products/xtar-aa-15v-2000mah-li-ion-battery) (>=1000 cycles); [Battery University BU-808](https://www.batteryuniversity.com/article/bu-808-how-to-prolong-lithium-based-batteries) (DoD vs cycle life data).

### 9. Battery Failure Rate

| Metric | A: Li-ion AA | B: LiPo Pouch | C: 18650 |
|---|---|---|---|
| **Catastrophic failure (thermal runaway)** | ~1 in 10 million (quality cells) | ~1 in 10 million (quality cells) | ~1 in 10 million (quality cells) |
| **Counterfeit/low-quality risk** | Moderate (niche market, limited manufacturers) | Moderate (variable quality from Chinese suppliers) | **High if not from reputable manufacturer** -- [Lumafield](https://www.lumafield.com/battery-report) found 1 in 13 (8%) of low-cost cells had dangerous anode overhang defects |
| **Primary failure mode** | USB-C port mechanical damage in tight battery compartments; buck converter PCB failure | Swelling/gas generation leading to seal rupture | Capacity fade; counterfeit cells with poor quality control |
| **Manufacturing quality data** | No published data specific to this format | Limited published data | Extensive ([Lumafield Battery Quality Report](https://www.lumafield.com/battery-report): >1000 cells CT-scanned) |

Sources: [Battery University BU-304a -- Li-ion safety and failure rates](https://www.batteryuniversity.com/article/bu-304a-safety-concerns-with-li-ion) ("failure rate of a quality Li-ion cell is better than 1 in 10 million"); [Lumafield Battery Quality Report](https://www.lumafield.com/battery-report) (1054 cells CT-scanned, 8% defect rate in low-cost cells).

### 10. Disinfection Suitability

The device is intended for clinical use in hospitals and must withstand repeated surface disinfection (wiping with chlorine-based solutions, alcohol, or quaternary ammonium compounds). Ingress of liquid into the enclosure during disinfection is a primary concern.

| Metric | A: Li-ion AA | B: LiPo Pouch | C: 18650 |
|---|---|---|---|
| **Battery access point** | Removable battery flap/door on enclosure rear | None (battery is sealed inside) | None (battery is sealed inside) |
| **USB-C port on enclosure** | **Not present** -- charging is on the battery itself | **Exposed** -- required for charging and flashing | **Exposed** -- required for charging and flashing |
| **Ingress risk during disinfection** | **Battery flap:** seam around the flap door is a liquid ingress path. Flap may be lost, left open, or improperly re-seated after battery swap, exposing the battery bay. Repeated disinfection degrades flap gasket/seal over time. | **USB-C port:** open cavity that must be covered with a silicone plug or hinged rubber cap during disinfection. Plug may be lost or forgotten. Port is recessed but not sealed. | **Same as B** |
| **Mitigation options** | Captive flap with living hinge (PETG compatible); silicone gasket around seam; IP-rated battery door latch | Silicone dust/splash plug for USB-C; hinged TPU cap molded into enclosure; conformal coating on PCB near port | Same as B |
| **Risk of component loss** | **High** -- flap/door is a separate part that can be lost, broken, or not re-attached after battery replacement in a busy ward | **Moderate** -- silicone USB-C plug is small and easily lost; a moulded captive cap reduces but does not eliminate risk | **Moderate** -- same as B |
| **Seal integrity over device lifetime** | Degrades with each battery swap (hundreds of open/close cycles over 1000+ charge cycles) | Degrades only with cap removal for charging (less frequent than battery swaps) | Same as B |
| **Overall disinfection suitability** | **Worst** -- two ingress paths (flap seam + battery contacts exposed when flap lost) | **Moderate** -- single ingress point (USB-C), manageable with captive cap | **Moderate** -- same as B |

Note: In all three scenarios, the optical sensor arm (IR LED + photodiode facing the drip chamber) is inherently exposed and must tolerate splash disinfection. The Thesis 1 enclosure (PETG, 3D-printed) already demonstrated chemical compatibility with common hospital disinfectants (Catarci, 2025, Section 2.1.3, thesis_1.pdf). The critical differentiator is the number and type of openings that must be sealed. Scenario A trades USB-C port exposure for a battery flap that is mechanically stressed during every battery swap. Scenarios B and C have a single, smaller opening (USB-C port) that is only accessed during charging, not routine battery replacement.

### 11. Administrative Ease of Battery Transport (Shipped in Device)

When shipping complete devices with batteries installed (PI 967, Section II), administrative requirements are simplified compared to shipping batteries separately. However, the three scenarios differ in practical burden.

| Metric | A: Li-ion AA | B: LiPo Pouch | C: 18650 |
|---|---|---|---|
| **Energy per cell** | 2.6-4.1 Wh | 3.7 Wh | 10.8-12.1 Wh |
| **2026 SoC shipping limit applies? (PI 967, in device)** | **No** -- PI 967 is exempt from the [2026 30% SoC limit](https://www.lion.com/lion-news/december-2025/new-lithium-battery-state-of-charge-limit-in-effect-jan-1) | **No** -- same exemption | **No** -- same exemption |
| **Shipper's Declaration for DG** | Not required | Not required | Not required |
| **Marking requirements** | Lithium battery handling label on outer package; UN3481 marking | Same | Same |
| **Max cells per package (PI 967, Section II)** | No limit on number of devices per package (each device contains 1 cell <20 Wh) | Same | Same |
| **Gross package weight limit** | 5 kg per package (Section II) | 5 kg per package | 5 kg per package |
| **Devices per 5 kg package (estimated)** | ~60-70 devices (device ~70 g each) | ~60-70 devices (~75 g each) | ~50-55 devices (~95 g each) |
| **Spare batteries shipped alongside** | Can ship spare Li-ion AAs **and** alkaline AAs easily; Li-ion AAs under 2.7 Wh may be exempt from 2026 SoC limit even under PI 966 | Spare pouch cells require PI 965 Section IB (full DG documentation, since PI 965 Section II was eliminated in 2022) if shipped alone; or PI 966 with 30% SoC limit if packed with equipment | Same restrictions as B for spare 18650 cells |
| **Practical advantage** | **Best** -- spare alkaline AAs are not regulated as dangerous goods at all (not lithium-ion). Spare Li-ion AAs are small enough to often fall under de minimis thresholds. Simple logistics. | Spare LiPo cells shipped alone require full DG paperwork. Most practical to pre-install and ship in device. | Spare 18650 cells are common cargo (flashlight/solar industry) so logistics providers in Africa are familiar with handling them. Easier than LiPo despite same regulatory classification. |
| **Customs familiarity** | AA batteries are universally recognised; customs officers unlikely to flag or delay | Pouch cells are less familiar; may trigger inspection or questions at customs in some countries | 18650 cells are familiar in the solar/flashlight supply chain; moderate customs familiarity |
| **Overall administrative ease** | **Easiest** -- especially with alkaline AA fallback (zero DG burden for spares) | **Hardest** -- unfamiliar form factor, full DG paperwork for spare cells | **Moderate** -- familiar in African supply chain, but full DG paperwork for spares |

Note: For all three scenarios, shipping the complete assembled device (battery installed) under PI 967 Section II is the simplest pathway. No Shipper's Declaration, no 2026 SoC limit, just a lithium battery handling label. The key differentiator is what happens when spare batteries need to be shipped separately for field replacement -- this is where Scenario A has a clear advantage because alkaline AAs carry zero dangerous goods burden, and the Li-ion AA cells are small enough (2.6-4.1 Wh) to minimise regulatory friction.

Sources: [IATA Lithium Battery Guidance Document (2026)](https://www.iata.org/contentassets/05e6d8742b0047259bf3a700bc9d42b9/lithium-battery-guidance-document.pdf); [Lion Technology: 2026 SoC limit advisory](https://www.lion.com/lion-news/december-2025/new-lithium-battery-state-of-charge-limit-in-effect-jan-1); [Intertek: UN 38.3 testing requirements](https://www.intertek.com/batteries/un-38-3-testing/); [Compliance & Risks: Battery regulation in Africa](https://www.complianceandrisks.com/blog/the-state-of-play-batteries-regulation-across-africa/).

---

## Additional Metrics

### 12. Enclosure Size Impact

| Metric | A: Li-ion AA | B: LiPo Pouch | C: 18650 |
|---|---|---|---|
| **Battery dimensions** | 14.5 x 50.5 mm (standard AA) | 6 x 34 x 53 mm (603450 format) | 18 x 65 mm |
| **Battery volume** | ~8.4 mL | ~10.8 mL | ~16.5 mL |
| **Fit in current enclosure (105x38x55 mm)** | **Yes** -- same as Thesis 1 design | **Yes** -- thinner, could enable slimmer enclosure | **Tight fit** -- 65 mm length may require enclosure lengthening or diagonal placement |
| **PCB impact** | Simplest PCB (no USB-C, no charger IC) | Requires USB-C connector, charger IC, NTC, battery connector on PCB | Same as B |
| **Enclosure redesign needed?** | **No** (direct AA holder swap) | Moderate (new battery compartment shape, USB-C cutout) | **Yes** (larger battery bay + USB-C cutout) |

### 13. Weight

| Component | A: Li-ion AA | B: LiPo Pouch | C: 18650 |
|---|---|---|---|
| **Battery weight** | Paleblue: 18.6 g / XTAR: ~19 g | ~20-22 g (with PCM + NTC) | **44-48 g** |
| **Additional PCB components** | Minimal (boost converter only) | BQ25185 + TPS631000 + USB-C + passives: ~2-3 g | Same as B: ~2-3 g |
| **Estimated total device weight impact vs Thesis 1** | **Baseline** (same as current) | **+2-3 g** (similar battery weight, added PCB components) | **+27-30 g** (heavier battery + added PCB components) |

Note: For a clip-on device on a drip chamber, weight directly affects grip stability. The 18650 adds significant mass which may require a stronger clamp mechanism. Thesis 1 enclosure was ~28 g (PETG). The current device with AA battery totals approximately 65-75 g. Adding an 18650 would push it to ~90-100 g.

Sources: [Paleblue tech specs](https://paleblueearth.com/pages/tech-specs) (18.6 g); [XTAR 3300 mWh specs](https://xtardirect.com/products/xtar-aa-15v-2000mah-li-ion-battery) (19 g); [Panasonic NCR18650B datasheet](https://www.batteryspace.com/prod-specs/ncr18650b.pdf) (47.5 g).

### 14. Charging Time (Empty to Full)

| Metric | A: Li-ion AA | B: LiPo Pouch | C: 18650 |
|---|---|---|---|
| **Charge rate** | Built-in charger: Paleblue 1.9 h / XTAR USB-C 2.7 h | 0.5C-1C ([BQ25185](https://www.ti.com/lit/ds/symlink/bq25185.pdf) at up to 1A) | 0.5C ([BQ25185](https://www.ti.com/lit/ds/symlink/bq25185.pdf) at 1A max) |
| **Time to full charge** | **1.5-2.7 hours** | **1-1.5 hours** (fastest) | **3-4 hours** |
| **Can device operate while charging?** | No (battery must be removed to charge via its own USB-C port) | **Yes** (BQ25185 power path) | **Yes** (BQ25185 power path) |

Note: Scenario A requires removing the battery from the device to charge it, creating downtime unless a spare battery is available. Scenarios B and C allow simultaneous charging and operation via the BQ25185 power path management.

Sources: [XTAR AA 4100 mWh USB-C](https://www.xtar.cc/product/xtar-aa-lithium-4100mwh-2450mah-usb-c-battery-with-low-voltage-indicator.html) (2.7 h charge time); [BQ25185 datasheet](https://www.ti.com/lit/ds/symlink/bq25185.pdf) (1A max charge current, power path management).

### 15. Temperature Operating Range

| Condition | A: Li-ion AA | B: LiPo Pouch | C: 18650 |
|---|---|---|---|
| **Charging range** | 0 to 45 C | 0 to 45 C | 0 to 45 C |
| **Discharging range** | -20 to 60 C | -20 to 60 C | -20 to 60 C |
| **Optimal operating** | 20 to 40 C | 20 to 40 C | 20 to 40 C |
| **Hot climate concern (35-50 C ambient)** | **Worst** -- internal buck regulator adds heat + continuous parasitic drain accelerates degradation | Moderate -- good heat dissipation (flat geometry) but seal integrity degrades with temperature cycling | **Best** -- robust steel can, best thermal tolerance, lowest self-discharge at elevated temp |
| **Calendar aging at 45 C (capacity loss rate)** | ~4-8x rate vs 25 C | ~4-8x rate vs 25 C | ~4-8x rate vs 25 C (but starts from lowest base self-discharge) |

Sources: [Battery University BU-808](https://www.batteryuniversity.com/article/bu-808-how-to-prolong-lithium-based-batteries) (temperature impact on cycle life); [Nature Scientific Reports: Temperature aging of Li-ion](https://doi.org/10.1038/srep12967); Arrhenius model with Ea ~ 36,000 J/mol.

### 16. PCB Complexity

| Metric | A: Li-ion AA | B: LiPo Pouch | C: 18650 |
|---|---|---|---|
| **Power ICs on PCB** | 1 (boost converter only) | 3 (BQ25185 + TPS631000 + CH340C for USB-UART) | 3 (same as B) |
| **USB-C connector** | Not needed | Required | Required |
| **ESD protection** | Not needed | Required (USB data + 5V lines) | Required |
| **NTC thermistor** | Not needed (in battery) | Required (bonded to cell, connected to BQ25185 TS pin) | Required |
| **Battery connector** | Standard AA holder (through-hole) | JST/Molex connector (SMD) + wires to pouch cell | 18650 holder or spot-welded tabs |
| **Estimated additional passive components** | ~5 (boost converter passives: inductor, caps, resistors) | ~25-30 (charger passives + converter passives + ESD + USB) | ~25-30 (same as B) |
| **Design effort** | **Lowest** -- similar to Thesis 1 PCB | **Highest** -- requires careful layout for charger, buck-boost, USB, thermal pad | **High** -- same as B, but larger battery holder may affect layout |

### 17. Regulatory / Transport Considerations

| Metric | A: Li-ion AA | B: LiPo Pouch | C: 18650 |
|---|---|---|---|
| **UN38.3 testing required?** | Yes (but typically certified by battery manufacturer: Paleblue/XTAR) | Yes (must be arranged with cell supplier) | Yes (typically certified by manufacturer: Samsung, LG, Panasonic) |
| **IATA packing instruction** | PI 967 Section II (contained in equipment) | PI 967 Section II | PI 967 Section II |
| **Energy per cell** | 2.6-4.1 Wh (well under 20 Wh limit) | 3.7 Wh (under 20 Wh) | 10.8-12.1 Wh (under 20 Wh) |
| **2026 SoC shipping limit (>2.7 Wh)** | Most models under 2.7 Wh threshold -- **exempt** | Above 2.7 Wh -- **must ship at <=30% SoC** (PI 966 only, packed with equipment) | Above 2.7 Wh -- **must ship at <=30% SoC** (PI 966 only) |
| **Shipper's Declaration for DG** | Not required (Section II) | Not required (Section II) | Not required (Section II) |
| **African import duties** | Same as other Li-ion | Same | Same (0% duty in [SACU](https://www.globaltradealert.org/state-act/8509/sacu-import-tariff-decrease-on-lithium-batteries)/EAC) |

Note: When shipping the complete device with battery installed (PI 967), the 2026 SoC limit does not apply. It only applies to PI 966 (battery packed alongside but not inside equipment). Shipping the device assembled avoids this restriction for all three scenarios.

Sources: [IATA Lithium Battery Guidance Document (2026)](https://www.iata.org/contentassets/05e6d8742b0047259bf3a700bc9d42b9/lithium-battery-guidance-document.pdf); [Lion Technology: 2026 SoC limit](https://www.lion.com/lion-news/december-2025/new-lithium-battery-state-of-charge-limit-in-effect-jan-1); [Intertek: UN 38.3 testing](https://www.intertek.com/batteries/un-38-3-testing/); [Compliance & Risks: Battery regulation in Africa](https://www.complianceandrisks.com/blog/the-state-of-play-batteries-regulation-across-africa/).

---

## Summary Scorecard

| Metric | A: Li-ion AA | B: LiPo Pouch | C: 18650 | Winner |
|---|---|---|---|---|
| 1. Battery capacity | 2550-4100 mWh | 3700 mWh | 10,800-12,060 mWh | **C** |
| 2. Total IC + battery cost | $5.10-$9.85 | **$2.15-$3.15** | $2.85-$4.15 | **B** |
| 3. Energy density (Wh/kg) | 137-174 | 185 | **200-243** | **C** |
| 4a. Runtime best case | 19-31 days | 24 days | **71-80 days** | **C** |
| 4b. Runtime worst case | 1.5-2.5 days | 2.1 days | **6.3-7.0 days** | **C** |
| 5. African availability | 1/14 countries (+ AA fallback: 14/14) | 3/14 countries | **10+/14 countries** | **C** (A with fallback) |
| 6. Swelling risk | Low | **High** | **Very low** | **C** |
| 7. Self-discharge | **5-8%/month (worst)** | 3-5%/month | **1-3%/month (best)** | **C** |
| 8. Cycle life | **1000-1200 (best)** | 500+ | 300-500 | **A** |
| 9. Failure rate | No published data | ~1 in 10M; swelling common | ~1 in 10M; counterfeit risk | **Tie A/C** |
| 10. Disinfection suitability | **Worst** -- battery flap seam + flap loss risk | Moderate -- USB-C plug needed | Moderate -- USB-C plug needed | **B/C** |
| 11. Admin ease of transport | **Easiest** -- alkaline AA spares carry zero DG burden | Hardest -- unfamiliar form, full DG for spares | Moderate -- familiar in African supply chain | **A** |
| 12. Enclosure impact | **No redesign needed** | Moderate redesign | Redesign needed (larger) | **A** |
| 13. Weight | **~19 g (lightest)** | ~22 g | ~47 g (heaviest) | **A** |
| 14. Charging time | 1.5-2.7 h (battery removed) | **1-1.5 h (in-device)** | 3-4 h (in-device) | **B** |
| 15. Hot climate suitability | Worst | Moderate | **Best** | **C** |
| 16. PCB complexity | **Simplest** | Most complex | Complex | **A** |
| 17. Transport/regulatory | Easiest (exempt from 2026 SoC limit) | Standard | Standard | **A** |

---

## Key Tradeoff Analysis

**Scenario A** offers the simplest PCB design, lightest weight, best cycle life, easiest transport logistics, and a universal alkaline-AA fallback. However, the battery itself is expensive ($5-8), nearly impossible to source in Africa (only South Africa confirmed), has the worst self-discharge rate, worst disinfection profile (losable battery flap), and requires removing the battery from the device to charge it.

**Scenario B** offers the lowest total IC + battery cost, fastest charging with in-device operation, and a thin form factor. However, LiPo pouch cells carry the highest swelling risk, are the hardest to source in Africa (3/14 countries), have no fallback option, and result in the most complex PCB.

**Scenario C** dominates on capacity, runtime, energy density, availability in Africa, swelling safety, self-discharge, and hot-climate suitability. The main tradeoffs are higher weight (~47 g vs ~19 g), longer charging time (3-4 h), need for enclosure redesign, and complex PCB. The 18650 is the most readily available specialty battery across Africa due to widespread use in flashlights, solar lanterns, and power banks.

---

## Results at a Glance

Scenario A (Li-ion AA) is the simplest to implement:
- Lightest (~19 g), simplest PCB, no enclosure redesign
- Best cycle life (1000-1200 cycles)
- Universal alkaline AA fallback (available in all 14 countries)
- Tradeoff: most expensive battery ($5-8), near-impossible to source in Africa (only South Africa), worst self-discharge (5-8%/month due to internal regulator quiescencurrent), may have to remove battery to charge depending on the case design

Scenario B (LiPo pouch) is the cheapest:
- Lowest total IC + battery cost ($2.15-$3.15)
- Fastest charging (1-1.5 h) with in-device operation
- Tradeoff: highest swelling risk, very limited African availability (3/14), no fallback, most complex PCB

Scenario C (18650) is the strongest overall:
- Highest capacity (10,800-12,060 mWh) and runtime (6-80 days depending on mode)
- Best availability in Africa (10+/14 countries surveyed)
- Lowest swelling risk and self-discharge (1-3%/month)
- Best suited for hot climates
- Tradeoff: heaviest (~47 g), requires enclosure redesign, 3-4 h charge time

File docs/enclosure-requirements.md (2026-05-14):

# Enclosure Requirements — Dripito Monitor

Specification for the 3D-printed mechanical housing. Written as a hand-off
document for a follow-up MSc/BSc thesis or a Rev-C revision: this file
defines *what the enclosure must do*; the artefacts in
[`../enclosure/`](../enclosure/) are *how the current revision satisfies
those requirements*.

A successor revising the enclosure should not have to re-derive these
requirements from clinical interviews and catalogues — that work was done
once for Rev-B and is captured here. Update this file when adding,
removing, or reframing a requirement; do not silently invalidate it.

## How to read this document

- **shall** — mandatory. A revision that fails a `shall` is a regression.
- **should** — strongly recommended. Deviating requires written
  justification in the revision's design notes.
- **may** — optional / informational.
- Each requirement carries an ID (`REQ-x.y`). Future revisions can cite
  IDs in their commit messages and decision records to make
  satisfies/breaks traceable.

## Scope

The enclosure houses one Dripito monitor PCB plus its battery, LCD,
buttons, status LEDs, optical front-end (IR emitters and photodiodes),
and a holder for a clinical IV drip chamber. It is intended for use in
humanitarian healthcare settings — low-resource clinics, paediatric
wards, field deployments. The current revision is FDM-printed; downstream
revisions may be injection-moulded but the requirements below remain
material-agnostic where possible.

**Out of scope:** sterilisation requirements (the device contacts the IV
chamber externally only; no fluid path goes through the enclosure),
implantable-grade biocompatibility, IP67 immersion ratings, lifecycle >
2 years of continuous outdoor exposure.

---

## 1. Material requirements

- **REQ-1.1** The enclosure **shall** be printable from ASA
  (Acrylonitrile Styrene Acrylate). Rationale: superior UV resistance
  vs. PETG, lower warping vs. ABS, accepted humanitarian-deployment
  durability profile. See `decisions/enclosure-material.md`
  (forthcoming).
- **REQ-1.2** The enclosure **should** be printable in white filament.
  Rationale: lower solar heat absorption in high-ambient-temperature
  field settings; better visibility of dirt to prompt cleaning.
- **REQ-1.3** The geometry **shall not** require materials with thermal
  performance beyond ASA's working envelope (continuous use up to
  ~85 °C). A revision that requires a more demanding material must
  justify the substitution against the deployment-temperature use case.
- **REQ-1.4** The enclosure **may** be substituted with PA12 / nylon for
  injection-moulded production runs at higher unit volumes, provided
  REQ-1.1's UV-resistance equivalent is preserved.

## 2. Geometric / mechanical requirements

- **REQ-2.1** All electronic components on the Dripito Rev-B PCB
  (`../hardware/flow_monitor.kicad_pcb`) **shall** fit within the
  enclosure with ≥ 1 mm clearance between any component top surface and
  the enclosure interior wall.
- **REQ-2.2** PCB-to-enclosure mounting **shall** use M2 brass
  heat-set inserts. Threaded plastic posts are not acceptable
  (insufficient thread durability for repeated assembly during
  servicing).
- **REQ-2.3** Threaded fasteners **shall** be M2 button-head screws of
  length appropriate to the boss depth. Non-captive screws are
  acceptable.
- **REQ-2.4** The enclosure **shall** allow PCB removal and
  re-installation without destructive disassembly.
- **REQ-2.5** Snap-fit features **may** be used for non-load-bearing
  closures (e.g. the back shell) provided the snap features do not need
  to be defeated to access the PCB for service.
- **REQ-2.6** Wall thickness **shall** be ≥ 2.0 mm at any
  unsupported region; ≥ 1.5 mm where backed by a rib or boss.
- **REQ-2.7** The enclosure outer dimensions **should not** exceed
  150 mm × 100 mm × 60 mm. Hand-portability and shelf-fit in clinical
  trolleys constrain the upper bound.

## 3. Optical-path requirements

These requirements derive from the dual-beam drop-detection architecture
(see `architecture.md`, forthcoming). They are the most failure-sensitive
requirements: violating any of REQ-3.x produces silently bad data.

- **REQ-3.1** The drip chamber, when seated in the holder, **shall** sit
  in a fixed, repeatable position relative to the sensor arm. The
  chamber **shall** be referenced (datumed) against the rigid
  sensor-arm side of the holder, not centred between two compliant
  faces. Rationale: optical path length must remain constant
  irrespective of chamber outer diameter.
- **REQ-3.2** The sensor arm **shall** present two horizontal infrared
  optical paths through the drip chamber, separated vertically by a
  nominal `d` of 10.0 mm (CAD nominal). This separation is the basis of
  the dual-beam velocity model (see EXP-1 in `testing-and-validation.md`).
- **REQ-3.3** The board-to-board standard deviation of measured beam
  separation across an assembled batch **shall** be ≤ 1.0 mm. Higher
  variance is a print-tolerance issue and must be addressed before the
  affected boards are used for validation. (See EXP-1 verification
  procedure.)
- **REQ-3.4** The IR emitter and photodiode optical apertures **shall**
  align with the chamber drop column to within ±0.5 mm in both the
  horizontal and vertical axes when the chamber is seated.
- **REQ-3.5** Stray ambient light reaching the photodiode at any sun /
  room-lamp incidence **should** be attenuated such that the baseline
  ADC value drift over 60 s is < 5 % of the signal dip during a drop
  passage. (Quantitatively verified in EXP-5 EC-03.)
- **REQ-3.6** The optical bore in the sensor arm (housing the LED and
  PD) **shall** be printed with its axis vertical (parallel to the
  chamber drop column) so the bore wall forms a circular cross-section
  rather than a stair-stepped ellipse. This is a print-orientation
  requirement, not a CAD requirement, and must be carried into the
  per-part slicer settings.
- **REQ-3.7** Replacing or recalibrating the LED / PD pair **shall** be
  possible without disturbing the sensor-arm-to-chamber datum
  (REQ-3.1). Practically: the optics module should be a sub-assembly
  that can be removed and reinstalled within the same alignment
  tolerance.

## 4. Drip-chamber compatibility

- **REQ-4.1** The chamber holder **shall** accept ISO 8536-4-compliant
  drip chambers with outer diameter in the range **14–24 mm**. This
  range covers microdrip / paediatric (14–17 mm) and standard adult
  macrodrip (18–22 mm) classes plus a manufacturing tolerance buffer
  (22–24 mm). Source: `../docs/decisions/chamber-holder-mechanism.md`
  (forthcoming) → drip-chamber diameter survey.
- **REQ-4.2** Wide-body / transfusion chambers (25–30 mm OD) are
  **explicitly out of scope** for the Rev-B baseline. A future revision
  **may** support them via an interchangeable cradle insert reusing the
  same optical-bay interface (REQ-3.7).
- **REQ-4.3** The holder **shall** retain a chamber against accidental
  bumping at any orientation within ±15° of vertical. Falling out
  during use is unacceptable.
- **REQ-4.4** The holder **shall** allow chamber installation and
  removal one-handed by a clinician. Two-handed operation is a fail.
- **REQ-4.5** Chamber installation **should** be possible without
  disconnecting the IV line above or below the chamber.

## 5. Holder mechanism

- **REQ-5.1** The holder **shall** use a vertical-axis hinged-clamshell
  topology: a fixed body carrying the sensor arm, optics, and PCB; a
  hinged passive lid that captures the chamber against the fixed side.
  Rationale and prior art: `../docs/decisions/chamber-holder-mechanism.md`
  (forthcoming).
- **REQ-5.2** The hinge axis **shall not** carry electrical signals.
  No FFC, no wires across the hinge.
- **REQ-5.3** The lid **shall** include a compliant gripper face (e.g.
  silicone / TPE pads, or printed compliant flexure) sized to span the
  REQ-4.1 OD range without changing the chamber's referenced position
  on the fixed side (REQ-3.1).
- **REQ-5.4** The hinge axis **shall** be located on whichever lateral
  side of the holder does **not** carry the optical-bezel datum, so
  opening the lid never disturbs alignment.
- **REQ-5.5** Closure **may** be friction-only, magnetic, or a printed
  snap. Whichever is chosen, it must require positive intent to open
  (i.e. cannot self-open under gravity or vibration in normal use).

## 6. User-interface integration

- **REQ-6.1** The enclosure **shall** present an LCD viewing window
  sized for the DOGS164W-A 4×16 character LCD with a minimum 1 mm
  bezel margin around the active area.
- **REQ-6.2** Tactile-button cutouts **shall** be provided for all
  buttons present on the active firmware revision. For Rev-B (firmware
  `Dripito`) this is MUTE / MODE / RES (3 buttons). The cutout
  locations match the Rev-B PCB silk; future revisions update CAD as
  the PCB changes.
- **REQ-6.3** Buttons **shall** be operable with one finger by an adult
  clinician wearing nitrile examination gloves.
- **REQ-6.4** Status LED bezels (battery / mode indicators) **shall**
  be visible in indoor-fluorescent ambient lighting from a viewing
  distance of 1 m.
- **REQ-6.5** The buzzer aperture **shall not** attenuate the alarm
  tone by more than 6 dB(A) at 1 m relative to the un-enclosed PCB
  measurement.
- **REQ-6.6** A power switch / battery compartment **shall** be
  accessible without removing the PCB.

## 7. Power / battery integration

- **REQ-7.1** The enclosure **shall** house the AA-cell battery solution
  used by Rev-B (single AA Li-ion routed via FFC, see
  `../docs/decisions/battery-cell-size.md`, forthcoming).
- **REQ-7.2** Battery insertion / removal **shall** be possible without
  tools.
- **REQ-7.3** A future Rev-C may switch to an 18650 Li-ion cell. The
  enclosure **may** anticipate this by leaving room or providing an
  alternate battery-bay STL, but must not require the change.

## 8. Environmental / deployment requirements

- **REQ-8.1** The enclosure **shall** be wipe-cleanable with isopropyl
  alcohol (IPA, ≤ 70 %) and standard medical disinfectant wipes
  without crazing or visible degradation in routine clinical use.
- **REQ-8.2** The enclosure **should** target IP54 ingress protection
  as a design goal. IP54 is the design target, **not** a tested
  specification — Rev-B is **not** validated to IP54 and any claim of
  IP54 compliance must wait on quantitative testing.
- **REQ-8.3** The enclosure **shall** survive a 1 m drop onto vinyl
  flooring without functional damage. Cosmetic damage is acceptable.
- **REQ-8.4** Operating temperature range: 5 °C to 45 °C ambient.
  Storage: −10 °C to +60 °C.
- **REQ-8.5** The enclosure **should** carry no sharp edges or pinch
  points exposed to a clinician's hands during normal use or chamber
  installation.

## 9. Manufacturability requirements

- **REQ-9.1** All printed parts **shall** print on a hobbyist-class
  FDM printer with a build volume of 220 × 220 × 250 mm or larger
  (Prusa i3, Bambu A1, equivalent).
- **REQ-9.2** No part **shall** require dissolvable / soluble support
  material. Standard tree / break-away supports only.
- **REQ-9.3** The print **should** complete each part in ≤ 8 hours on
  the reference printer at the documented profile, to support iterative
  development cycles.
- **REQ-9.4** Each printable part **shall** ship with a documented
  print profile in `../enclosure/print_settings/` (slicer ini/json
  plus per-part overrides).
- **REQ-9.5** Heat-set insert installation **shall** be documented:
  insert geometry, soldering iron tip, temperature, depth.
- **REQ-9.6** The full set of parts for one device **should** require
  ≤ 200 g of ASA filament.

## 10. Verification

How each requirement category is verified:

| Category | Verification | Where evidence lives |
|---|---|---|
| Material (REQ-1.x) | Print + visual inspection + IPA wipe test | `enclosure/print_history/` |
| Mechanical fit (REQ-2.x) | Test PCB inserted, screws torqued, snap features cycled 5× | `enclosure/print_history/` |
| Optical alignment (REQ-3.x) | EXP-1 caliper measurement of `d` per board; EXP-0 detection-gate test | `data/geometry.json`, `data/calibration_log.csv` |
| Chamber fit (REQ-4.x) | Physical fit test with 14, 18, 20, 22, 24 mm chambers (or shimmed phantoms) | `enclosure/print_history/` + `docs/limitations.md` |
| Holder mechanism (REQ-5.x) | One-handed install / remove demo, ±15° tilt retention test | `enclosure/print_history/` |
| User interface (REQ-6.x) | Gloved-hand button test, LCD-readability check at 1 m | `enclosure/print_history/` |
| Environmental (REQ-8.x) | IPA wipe, drop test from 1 m, ambient temp survey | `enclosure/print_history/` |
| Manufacturability (REQ-9.x) | Reference profile print on Prusa MK4 / Bambu A1; mass measurement | `enclosure/print_settings/` + `print_history/` |

## 11. Known gaps in the current Rev-B implementation

(To be filled in once the validation campaign 2026-05-07 → 2026-05-10
identifies which requirements the May-04 print fails. Each gap is then
either fixed in a Rev-B re-print, or accepted-with-rationale and entered
into `../docs/limitations.md`.)

## 12. Out of scope (and why)

- **Sterilisation cycles (autoclave, EtO, gamma).** The device contacts
  the chamber externally only; the IV fluid path is closed. Surface
  cleaning (REQ-8.1) is sufficient.
- **IP67 immersion.** Field-clinic deployment does not require
  immersion resistance. IP54 design target (REQ-8.2) is the maximum
  ingress claim.
- **Wide-body / transfusion chambers (25–30 mm OD).** Excluded from
  REQ-4.1 to keep the holder simple. A future revision may revisit.
- **Integration with peristaltic pumping.** Dripito monitors gravity
  infusion only.
- **Continuous outdoor exposure > 2 years.** ASA's UV resistance is
  good but not infinite; the device is intended for indoor /
  shaded clinical use with occasional transport.
- **Conformity assessment for medical-device certification (CE, FDA).**
  Out of scope for Rev-B as a research artefact; flagged in
  `../docs/recommendations.md` (forthcoming) as a Rev-C / commercial
  requirement.

## Cross-references

- Validation procedure (incl. EXP-1 geometry):
  [`testing-and-validation.md`](testing-and-validation.md)
- Decision records (forthcoming):
  - `decisions/enclosure-material.md`
  - `decisions/chamber-holder-mechanism.md`
  - `decisions/sensor-arm-alignment.md`
  - `decisions/back-casing-extrude.md`
  - `decisions/battery-cell-size.md`
- Current artefact set: [`../enclosure/`](../enclosure/)
- Drip-chamber diameter survey (basis for REQ-4.1): summarised in
  `decisions/chamber-holder-mechanism.md` (forthcoming).

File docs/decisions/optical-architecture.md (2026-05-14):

# Optical Architecture — Dual-Beam Phase 1 + LPTIM1 Single-Beam Phase 2

**Date:** 2026-03-15

## Context

Rev-A used a continuous single-beam optical drop detector with a fixed assumed drop volume (50 µL for macro 20 gtt/mL drip sets). This fixed-volume assumption was the dominant source of flow-rate error in Rev-A, because real drop volumes vary with drip-set geometry, fluid surface tension, and drip rate (Tate's-Law dependence). Rev-B has two design constraints that drove the optical-architecture decision: (1) the system must accept any standard macro/micro/neonatal drip set without manual configuration, and (2) the device must run on a single Li-ion AA for multi-week sessions (see [`power-architecture.md`](power-architecture.md)), forcing aggressive duty-cycling of the IR emitters.

## Decision

The Rev-B optical chain uses a two-phase approach:

- **Phase 1 — calibration (first ~10 drops after boot).** Both IR beams (TOP and BOT, 10 mm vertical separation) run simultaneously. Per drop, the firmware measures transit time between the two beam crossings and pulse width on each beam to infer drop volume from a sphere-model chord-time calculation. This delivers a per-session, drip-set-agnostic empirical drop volume tied to the actual fluid and chamber in use.
- **Phase 2 — continuous monitoring.** Once Phase 1 has converged on a stable volume estimate, the device switches to single-LED operation. LPTIM1 drives a low-duty pulse train on the BOT beam; the internal COMP1 wakes the MCU on each drop crossing. The TOP beam is unused in Phase 2. This gates the IR LED average current to ~57 µA (0.3 % duty at 19 mA peak), enabling the multi-week runtime target.

## Alternatives considered

- **Rev-A approach — single-beam continuous, fixed assumed drop volume.** Lost on accuracy: the fixed 50 µL/drop assumption is the dominant Rev-A error term, and any device claiming flow-rate measurement across drip sets must measure (not assume) drop volume.
- **External ADC sampling against firmware threshold (no internal comparator) as the Phase 2 architecture.** Lost on power: continuous ADC sampling consumes more average current than the comparator-on-wake-up architecture, and the ADC dynamic range is wasted on what is fundamentally a one-bit transit event. (Rev-B Phase 1 — the per-session calibration window — does use ADC polling on both photodiodes; the power-loss argument applies only to the multi-week-runtime Phase 2 mode.)
- **Permanent dual-beam continuous operation.** Lost on power: running both IR LEDs continuously at the duty cycle Phase 1 needs would prevent multi-week runtime on a single AA. The dual-beam phase is the price paid for per-session calibration; minimising its duration (~10 drops) keeps the energy cost bounded.

## Consequences

- **Drip-set-agnostic.** The user does not configure a drip-set type. The device measures it. This is the central UX simplification vs Rev-A and the dominant accuracy lever.
- **Calibration is per-session, not per-device.** Every boot re-runs Phase 1. This is robust against drip-set swaps and fluid changes mid-deployment without firmware support for explicit recalibration.
- **Target architectural accuracy ceiling: ~4–5 % systematic error.** This was the pre-bench prediction, vs Rev-A's ~10 %. As of the 2026-05-13 bench, the current Rev-B firmware + sensor-arm geometry achieves a residual of ±30 % per-run on the morning V_50 campaign (see [`../results.md`](../results.md)), dominated by drop-shape oscillation between oblate and prolate during free fall (see [`../limitations.md`](../limitations.md) §Drop-shape oscillation and §Position-dependence). The architectural ceiling of 4–5 % remains the design target; closing the gap to it requires algorithm rework on the chord-time estimator and likely a sensor-arm geometry that better controls drop trajectory through the beams. Whether the architectural ceiling is actually reachable in the Rev-B form-factor is open, and further bench iteration is needed to bound the achievable accuracy.
- **The Phase 1 / Phase 2 split couples firmware complexity to a transition trigger.** Phase 2 entry requires a stable Phase-1 estimate and depends on calibration convergence within the first ~10 drops; pathological drip-rate or geometry conditions can stall the transition. Documented as an open firmware path in [`auto-calibration-at-boot.md`](auto-calibration-at-boot.md).
- **Dual-LED layout buys a fault-tolerance side-benefit.** If one IR LED fails in field deployment, the firmware can fall back to single-beam operation on the surviving emitter — at the cost of Phase-1 calibration accuracy, but with the device still functional as a Rev-A-style counter. Not a design driver; recorded as a consequence worth keeping.

## Revisit triggers

- If bench iteration shows the chord-time architecture cannot close the gap from ±30 % to ~5 % even with algorithm rework + geometry control, the optical architecture itself reopens. Candidate replacements include horizontally-separated beams (resolves the sphere-from-vertical-chord ambiguity that drop oscillation creates) and TOP/BOT gain equalisation (see [`../limitations.md`](../limitations.md) §Position-dependence).
- If the Phase 1 / Phase 2 transition logic proves unreliable in field deployment, revisit the convergence criteria or merge to a single continuously-calibrating mode.
- If a future revision drops the dual-LED layout (e.g. for cost), the fault-tolerance consequence above is forfeited.

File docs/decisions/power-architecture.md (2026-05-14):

# Power Architecture — Single Li-ion AA via TPS610981 Boost

**Date:** 2026-03-24

## Context

The Rev-A device was powered by a Li-ion AA cell (Paleblue) boosted to 3.3 V by the TPS610981. The decision was reopened, an unbiased comparison was produced, and external clinical input was sought from Dr. Janis Tupesis (WHO EMT, deployment experience in Liberia, Haiti, Gaza) on field power realities.

The decision is mechanical (which cell + which boost converter) and a target metric of multi-week continuous battery life. The TPS610981 has near-identical regulation behaviour on AA and AAA, so cell **size** was decided separately (see [`battery-cell-size.md`](battery-cell-size.md)).

The decision-making process — supervisor pushback, Tupesis consultation, the solar feasibility investigation, and the personal reflection — is recorded separately in [`power-architecture-process.md`](power-architecture-process.md).

## Decision

Rev-B is powered by a **single rechargeable Li-ion AA cell (Paleblue) boosted to 3.3 V by the TPS610981**, with no on-PCB charging circuit (the AA cell is charged externally through its own USB-C port).

## Alternatives considered

- **18650 cylindrical cell (Smith schematic heritage).** Strongest on raw energy: 2.5–4.6× more usable capacity, $1.60–$4.55 cheaper per unit at 1000-unit scale, available in 10+/14 African countries vs 1/14 for rechargeable Li-ion AA, lower self-discharge, supports charge-while-operate via BQ25185 power path. Rejected for Rev-B because (a) a sealed internal cell with PCB-mounted charging puts wall-power transients onto the device electronics — Tupesis confirmed field power quality is dangerous (rolling blackouts, generator restarts, 220–240 V variation within a single building); (b) when the sealed cell fails after 1–2 years, the device gets discarded ("for a device this small — would get tossed in the garbage" — Tupesis); (c) higher PCB complexity (~25–30 power-section passives vs ~5 for AA), unvalidated Smith schematic, no Rev-A heritage; (d) heavier (47 g vs 19 g battery, ~90–105 g vs ~65–75 g total device — clip-on stability concern).
- **LiPo pouch cell.** Dropped by mutual agreement during supervisor review.
- **Integrated PCB-mounted solar harvesting (BQ25504 / AEM10941).** Investigated in depth (see process doc §5). Rejected for Rev-B on the grounds of **thermal safety** — a device in direct equatorial sun reaches 60–80 °C interior, above the 45 °C Li-ion charging ceiling, triggering IEC 60601-1 "reasonably foreseeable misuse" testing burden.

## Consequences

- **Surge resilience.** No charging circuit on the device PCB. Wall power touches the AA cell's own internal circuitry — not the medical device. This is the single biggest Tupesis-anchored argument for the AA architecture.
- **Field repairability.** Dead cell = swap a cell. The device is never bricked by a battery failure.
- **Alkaline AA fallback.** When the rechargeable cell is dead and no charging is available, the user can drop an alkaline AA in and the device runs as a consumable. Boost converter regulates either chemistry identically.
- **PCB simplicity.** ~5 passives in the power section vs ~25–30 for an 18650 + BQ25185 architecture. Faster bring-up, lower BOM, less debugging surface.
- **Honest cost paid:** 2.5–4.6× less usable energy than the 18650 path. The Phase 2 power budget (LCD always on + dual-IR-LED at 0.3 % duty + STM32G071 Stop 1) of ~190 µA at 3.3 V translates to ~700 µA from the cell at realistic boost efficiency (60 % at this load) → ~1 000 h claimable runtime on a Paleblue 2400 mAh cell. That is still ~3× the DripAssist benchmark (360 h), so the AA architecture clears the competitive bar (see [`battery-cell-size.md`](battery-cell-size.md)).
- **Lower African field availability for the rechargeable cell** (1/14 countries vs 10+/14 for the 18650). Mitigated by the alkaline AA fallback path.

The deployment model that surrounds this hardware choice — multi-unit field kit, alkaline fallback batteries, external solar charging — is captured separately in [`care-package-deployment.md`](care-package-deployment.md) and is **planned, not executed** for Rev-B.

## Revisit triggers

- If Rev-C drops the AA cell in favour of a LiPo or 18650 with on-PCB charging, revisit and produce a Rev-C-targeted comparison.
- If a future deployment context constrains the device to wholly battery-less (mains-powered) operation, revisit.
- If solar harvesting becomes a hard requirement, the AA architecture is structurally incompatible and the whole power stack reopens.
- If Phase 2 power budget grows beyond ~300 µA (e.g. always-on connectivity, more LEDs), the boost efficiency regime shifts and the AA runtime headroom may no longer justify the architecture.

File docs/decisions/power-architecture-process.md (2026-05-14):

# Power Architecture — Decision Process Record

**Date:** 2026-03-26 (process records 2026-03-17 → 2026-03-26)

> This is a record of *how* the power architecture decision was made — the supervisor pushback, the external clinical consultation, the solar feasibility investigation, and the methodology used to produce an unbiased comparison. The decision itself (Li-ion AA + TPS610981 boost) lives in [`power-architecture.md`](power-architecture.md).

## 1. Timeline

**17 March 2026** — Submitted a formal Energy Architecture Decision Matrix to supervisors Jakub Tkaczuk and Elia. The document compared three options: Li-ion AA (Option A), LiPo pouch cell (Option B), and a LiPo + alkaline AA hybrid with automatic power-path OR-ing (Option C). The matrix used 7 weighted criteria, a sensitivity analysis with tornado perturbation and 4 deployment scenarios, a 3-year TCO model, and a simplified FMEA. It recommended Option A — the rechargeable Li-ion AA with alkaline fallback.

**~20 March** — Received critical feedback from both Elia and Jakub. The core message from both reviewers was that the analysis was biased toward a pre-determined conclusion (Option A), disproportionate in depth relative to the decision, and missing the most obvious alternative (18650 cylindrical cell). Jakub noted that Option C (the hybrid) was an implausible strawman, and that the 18650 from Fionn Smith's V2 schematic was the natural third candidate. Elia flagged that the input data was skewed across multiple criteria and that the cost comparison used inconsistent sourcing.

**~21 March** — Responded to supervisors acknowledging the bias and proposing to consult Dr. Janis Tupesis for an independent clinical perspective. Jakub approved the approach and simultaneously shared his own AI-assisted power analysis covering 17 metrics across Li-ion AA, LiPo pouch, and 18650, sourced from LCSC, manufacturer datasheets, and a 14-country African availability survey. Its summary favoured the 18650 as the "strongest overall" option.
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

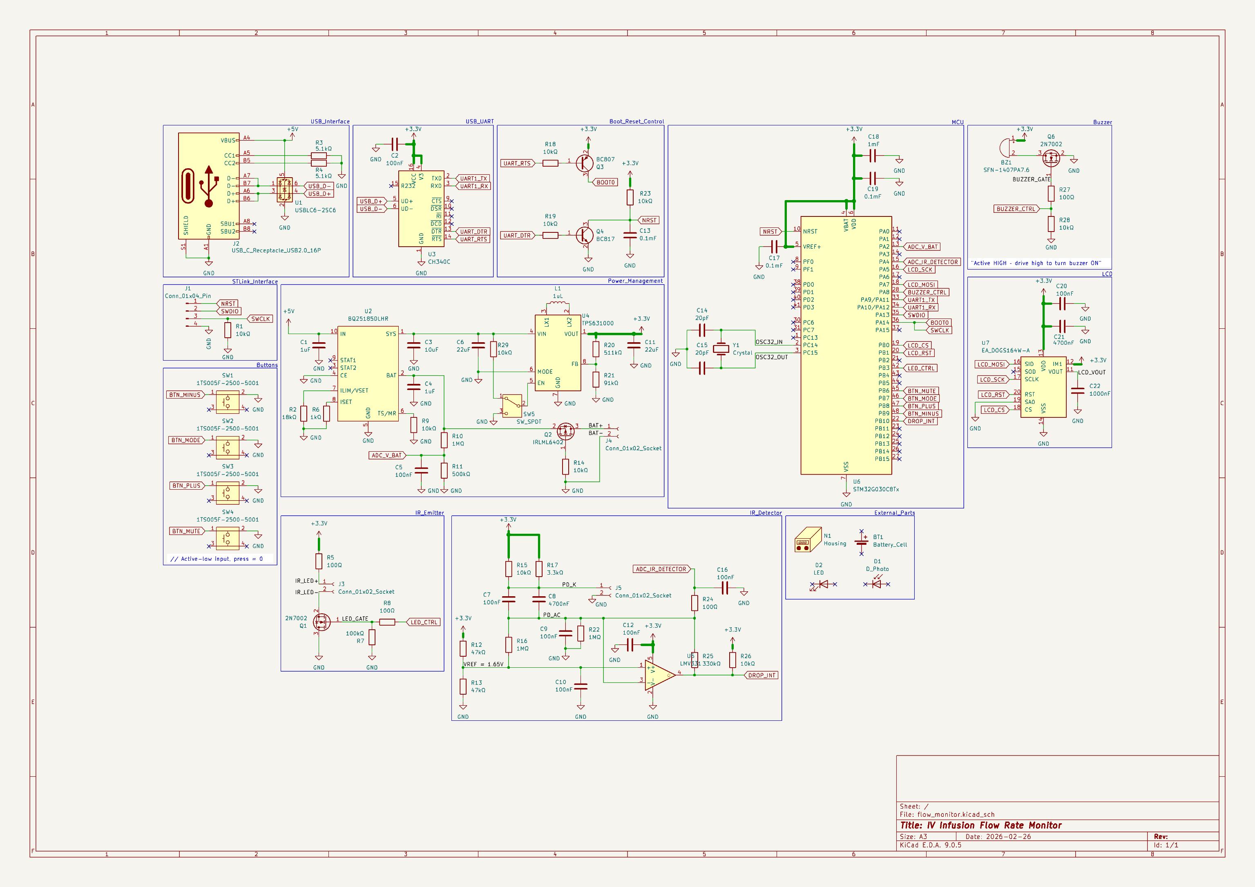
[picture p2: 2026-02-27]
media/schematic.jpg

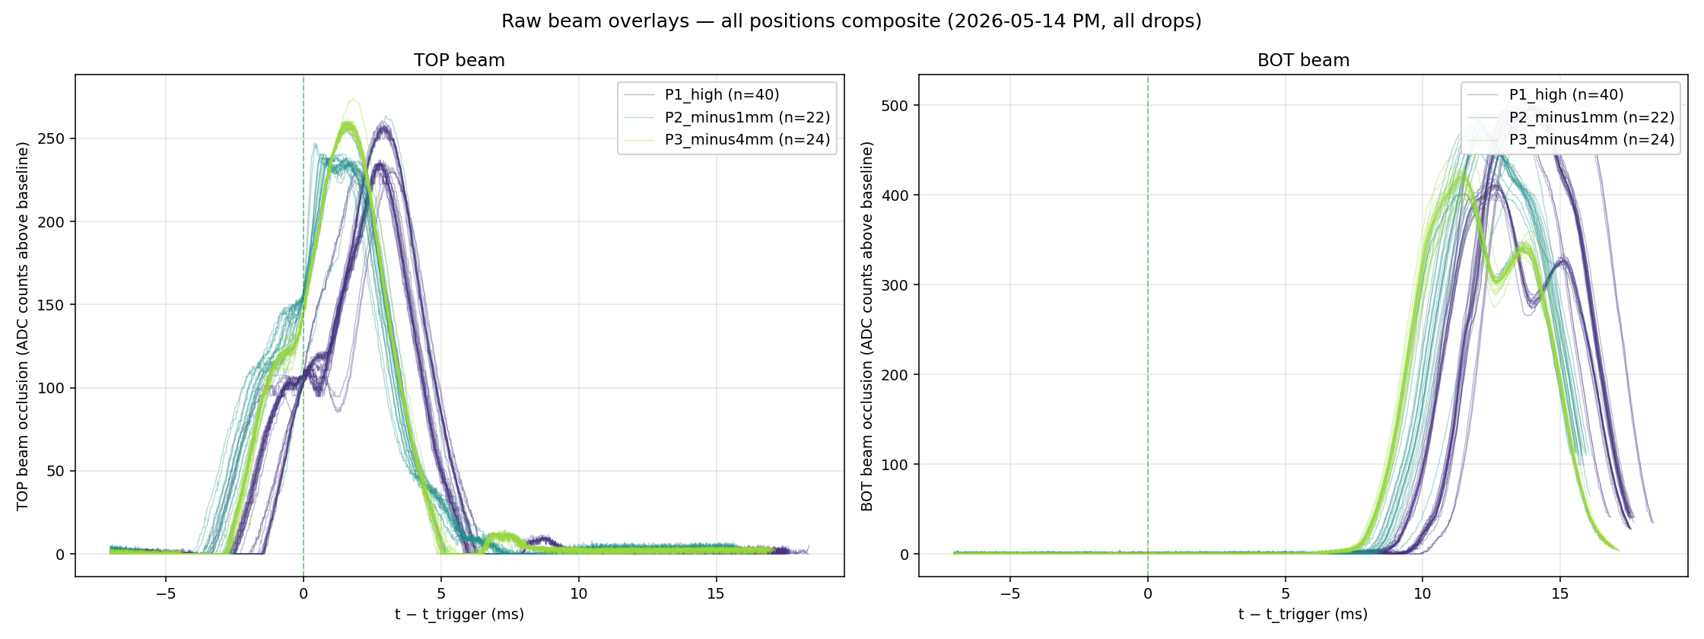
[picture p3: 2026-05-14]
analysis/figs/2026-05-14_pm/raw_overlays_all_positions.png

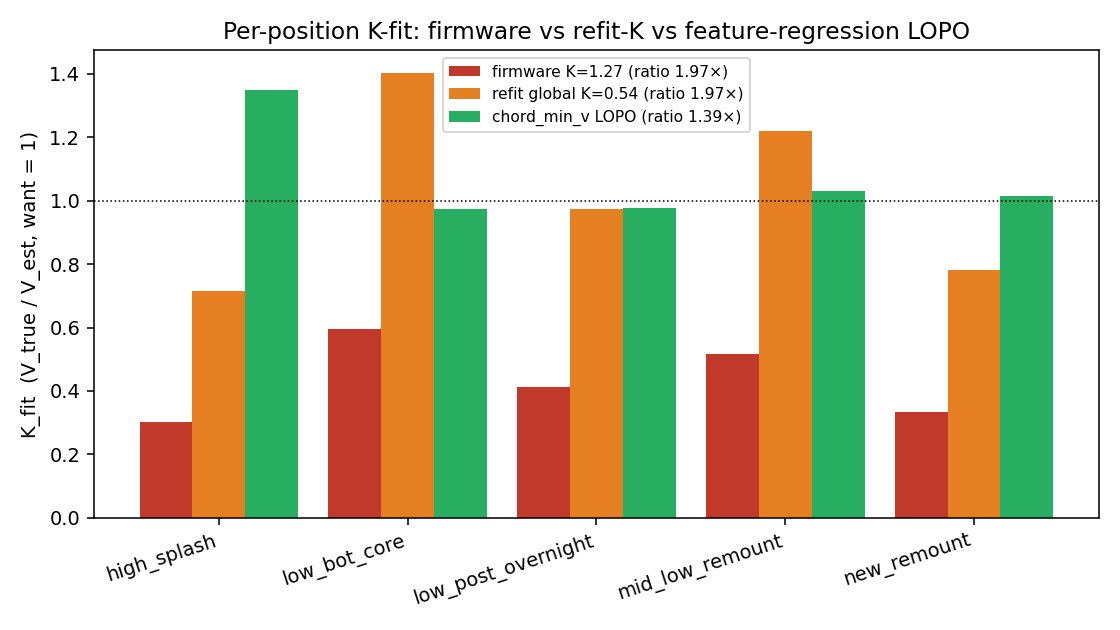
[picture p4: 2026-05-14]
analysis/figs/2026-05-14_pm/final/fig1_k_landscape_before_after.png

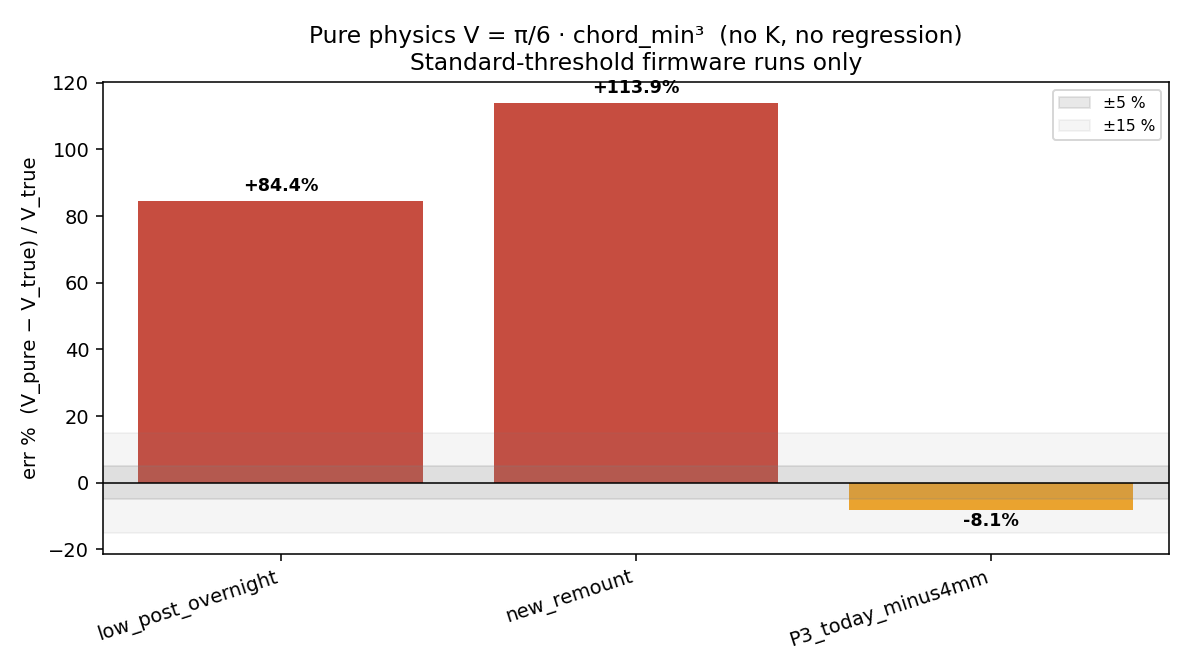
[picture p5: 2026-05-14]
analysis/figs/2026-05-14_pm/final/fig8_pure_physics_chord_min_cubed.png

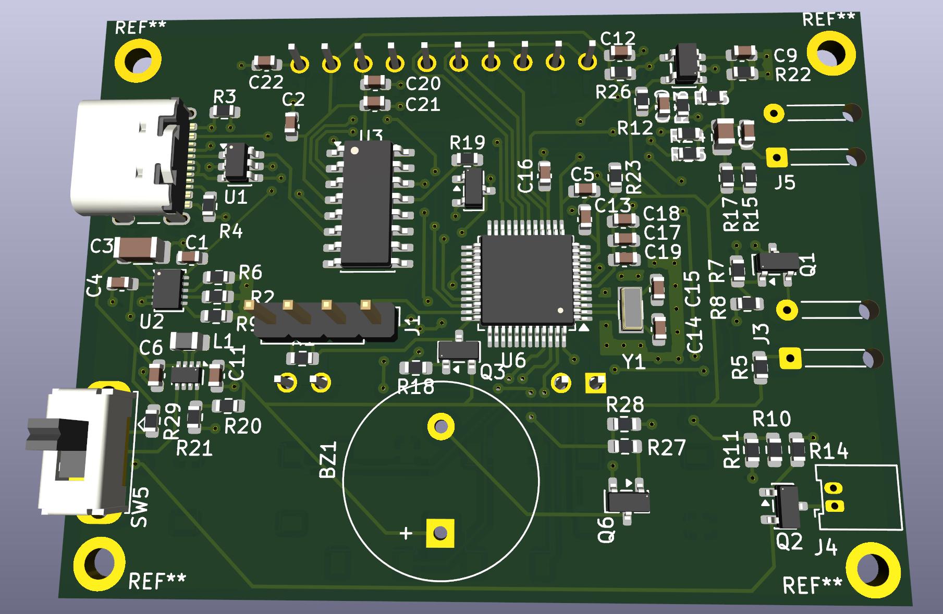
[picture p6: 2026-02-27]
media/3dmodel_back.jpg

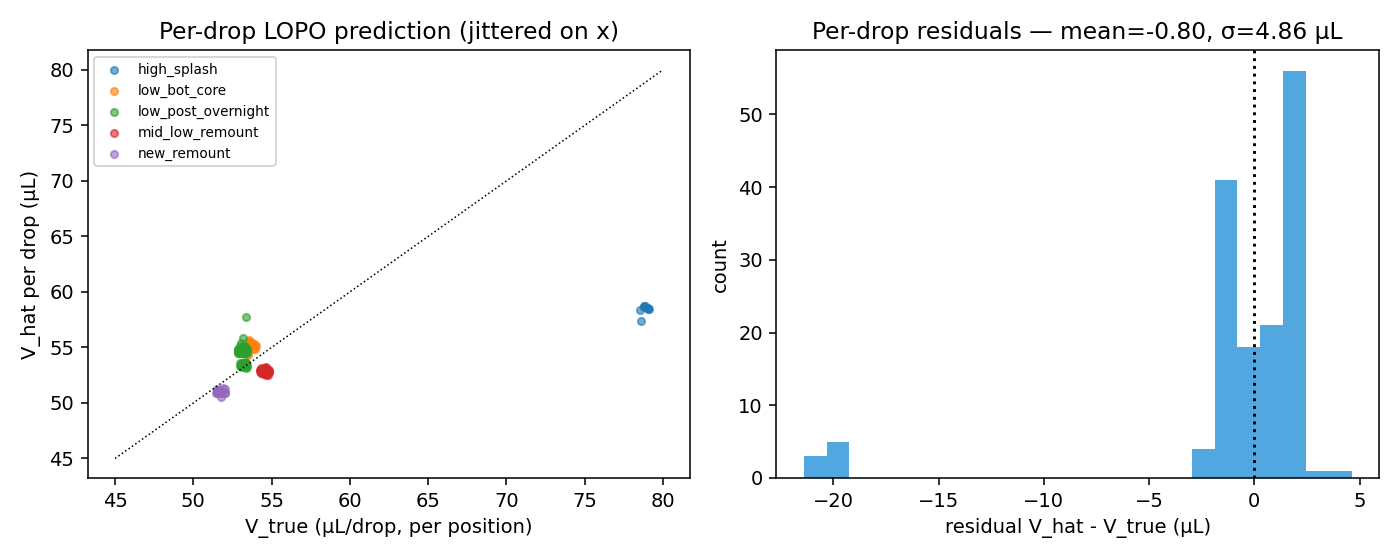
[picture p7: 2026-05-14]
analysis/figs/2026-05-14_pm/final/fig3_per_drop_residuals.png

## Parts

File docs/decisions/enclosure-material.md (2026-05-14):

# Enclosure Material — ASA White, FDM, Snap-Fit Assembly

**Date:** 2026-03-15

## Context

The Rev-B enclosure must protect the PCB, optics, and battery in a clip-on form factor for clinical use, fabricated at low cost in the 5-unit prototype batch and any subsequent small-volume production. The deployment context is humanitarian healthcare in regions with outdoor light exposure, high ambient temperature, and limited maintenance — UV resistance and warping behaviour during printing matter. The decision combines three coupled sub-decisions: filament material, colour, and fastener mechanism.

## Decision

The enclosure is fabricated by **FDM 3D printing in ASA (Acrylonitrile Styrene Acrylate), white**, with **snap-fit assembly** between body and lid. No threaded fasteners and no heat-set inserts are used.

## Alternatives considered

- **PETG (filament alternative).** Easier to print, similar cost, but lower UV resistance — relevant for outdoor humanitarian deployment, where the device may sit in sun-exposed environments.
- **ABS (filament alternative).** Comparable mechanical properties to ASA, but higher warping risk during FDM printing, especially for large flat surfaces like the back shell.
- **SLA / DLP resin.** Better surface finish than FDM, but higher per-unit cost and a brittle finished part that is less repairable in field conditions.
- **Injection moulding.** Lowest per-unit cost at scale, but tooling cost is not justified at the 5-unit prototype volume; reserved as a Rev-C-or-later option once design is locked.
- **M2 brass heat-set inserts + button-head screws (fastener alternative).** Adds parts, assembly time, and a heat-set installation step. Snap-fits eliminate this in exchange for a printed-geometry-tolerance dependency.

## Consequences

- **UV and weather resistance.** ASA's superior UV stability over PETG and ABS is the central material argument. White colouring further reduces solar heat absorption in high-ambient-temperature settings.
- **Snap-fit assembly.** No screws, no inserts, no separate fasteners to ship with each unit. Assembly time and BOM both reduced. The trade-off is that snap-fit reliability depends on print tolerance — the same FDM ±0.2 mm geometry variability that limits sensor-arm alignment ([`sensor-arm-alignment.md`](sensor-arm-alignment.md)) shows up here too. Disassembly for service requires either flexing the snap-fit lugs or accepting that the enclosure is functionally non-serviceable.
- **Print warping risk reduced (vs ABS).** ASA still requires an enclosed chamber, heated bed (~100 °C), and ~250 °C nozzle, but warping behaviour is more forgiving for the long flat sections in the back shell.
- **Cost.** ASA filament is similar to PETG and ABS per kg (~CHF 30–40), much cheaper than SLA per finished part.

## Outlook (aspirational, not validated for Rev-B)

- **IP54 ingress protection** is a design aspiration for the enclosure form factor — moderate dust intrusion + splash resistance, appropriate for a bedside clinical device. **Rev-B has not been tested against IEC 60529 for IP54 compliance.** The snap-fit joint geometry, optical-bezel sealing, and any cable / button penetrations are unvalidated against ingress. The aspiration is recorded so a Rev-C or follow-up thesis can design and test against it explicitly.

## Revisit triggers

- If the snap-fit reliability proves insufficient in field deployment (lugs failing, repeated open/close cycles loosening the joint), revisit fastener mechanism — heat-set inserts + screws is the natural fallback.
- If a future revision targets actual IEC 60529 IP54 certification, the snap-fit joint geometry, bezel sealing, and button sealing all reopen as design parameters.
- If ASA filament becomes unavailable or significantly more expensive than alternatives, PETG with a UV-stabilised additive is the next option.
- If production scale crosses the threshold where injection-moulding tooling pays back, the FDM-tolerance constraints disappear and the whole material + fastener stack reopens.

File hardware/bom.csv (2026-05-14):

group | ref | category | description | manufacturer | mfg_pn | lcsc_pn | digikey_pn | footprint | qty_per_unit | price_usd_1 | price_usd_1k | datasheet | notes
pcb | U2 | IC | STM32G071C8T6 Cortex-M0+ MCU | STMicroelectronics | STM32G071C8T6 | C529341 |  | LQFP-48_7x7mm_P0.5mm | 1 | 1.6543 | 0.8300 |  | Migrated from G030/G031 (lack COMP1+DAC) | qty=1000 estimate (~50% of LCSC qty=1)
pcb | U1 | IC | TPS610981DSET 1.5-to-3.3V boost | Texas Instruments | TPS610981DSET | C73820 |  | DSE0006A | 1 | 1.1171 | 0.6100 |  | Single-cell Li-ion AA boost | qty=1000 estimate (~50% of LCSC qty=1)
pcb | U3 | Display | EA DOGS164W-A 4x16 transflective LCD | Display Visions | EA DOGS164W-A |  | 1481-1306-ND | EA_DOGS164X-A | 1 | 7.1667 | 4.30 |  | DigiKey CHF 6.45 each (2026-04-02 invoice) | qty=1000 estimate ~40% discount
pcb | Y1 | Crystal | 32.768 kHz LSE crystal | YXC | X321532768KGD2SI | C620155 |  | Crystal_SMD_3215-2Pin_3.2x1.5mm | 1 | 0.1993 | 0.1200 |  | RTC reference | qty=1000 estimate (~50% of LCSC qty=1)
pcb | Q3 | Transistor | AO3401A P-channel MOSFET | Alpha & Omega | AO3401A | C347476 |  | SOT-23 | 1 | 0.0286 | 0.0230 |  | qty=1000 estimate (~50% of LCSC qty=1)
pcb | BZ1 | Audio | SFN-1407PA7.6 piezo buzzer | Sonitron | SFN-1407PA7.6 | C360603 |  | Buzzer_S&S_SFN-1407PA7.6 | 1 | 0.0617 | 0.0430 |  | Driven by Q4 with R17 pull-up | qty=1000 estimate (~50% of LCSC qty=1)
pcb | L1 | Inductor | LQM21PN4R7MGRD 4.7 uH boost inductor | Murata | LQM21PN4R7MGRD | C86090 |  | L_0805_2012Metric | 1 | 0.0649 | 0.0420 |  | qty=1000 estimate (~50% of LCSC qty=1)
pcb | C1 | Capacitor | 10 uF GRM188R60J106ME47D | Murata | GRM188R60J106ME47D | C77041 |  | C_0603_1608Metric | 1 | 0.0088 | 0.0070 |  | Boost output | qty=1000 estimate (~50% of LCSC qty=1)
pcb | TP1+TP2 | Test point | Keystone 5000 miniature test point | Keystone | 5000 | C5199900 |  | TestPoint_Keystone_5000-5004_Miniature | 2 | 0.2683 | 0.1480 |  | qty=1000 estimate (~50% of LCSC qty=1)
pcb | J4 | Connector | FPC-05F-6PH20 6-pin 0.5 mm FFC socket | Jushuo | FPC-05F-6PH20 | C2856796 |  | Jushuo_AFC07-S06FCA-00_1x6-1MP_P0.50_Horizontal | 1 | 0.0784 | 0.0550 |  | Battery + IR LED satellite | qty=1000 estimate (~50% of LCSC qty=1)
pcb | SW1 | Switch | SK12D07VG5 SPDT slide switch | C&K | SK12D07VG5 | C431548 |  | X_SW_Slide_SPDT_SSK12D07VG5 | 1 | 0.0204 | 0.0160 |  | qty=1000 estimate (~50% of LCSC qty=1)
pcb | S1+S2+S3 | Switch | PTS647SN38 tactile switch (Reset/Mode/Mute) | C&K | PTS647SN38SMTR2 LFS |  | 108-PTS647SN38SMTR2LFSCT-ND | SW_SPST_PTS647_Sx38 | 3 | 0.2022 | 0.13 |  | DigiKey CHF 0.182 each (2026-04-02 invoice); excluded from PCBA, hand-soldered | qty=1000 estimate ~30-50% DigiKey volume
pcb | J1 | Connector | PM254-1-07-Z-8.5 7-pin header | XKB | PM254-1-07-Z-8.5 | C2897370 |  | PinHeader_1x07_P2.54mm_Vertical | 1 | 0.1227 | 0.0680 |  | SWD + USART1 | qty=1000 estimate (~50% of LCSC qty=1)
pcb | C3 | Capacitor | 100 nF GCM188R71H104KA57D (HF) | Murata | GCM188R71H104KA57D | C85864 |  | C_0603_1608Metric | 1 | 0.0097 | 0.0080 |  | qty=1000 estimate (~50% of LCSC qty=1)
pcb | C5+C9+C10+C12+C14 | Capacitor | 0.1 uF CL10B104KB8NNNC decoupling | Samsung | CL10B104KB8NNNC | C1591 |  | C_0603_1608Metric | 5 | 0.0024 | 0.0020 |  | qty=1000 estimate (~50% of LCSC qty=1)
pcb | C2 | Capacitor | 100 nF CL10B104KA8NNNC | Samsung | CL10B104KA8NNNC | C1590 |  | C_0603_1608Metric | 1 | 0.0031 | 0.0020 |  | qty=1000 estimate (~50% of LCSC qty=1)
pcb | J2+J3 | Connector | 2.54 mm 1x2 photodiode socket | BOOMELE | 2.54-1*2P母 | C49661 |  | PinSocket_1x02_P2.54mm_Vertical | 2 | 0.0354 | 0.0250 |  | qty=1000 estimate (~50% of LCSC qty=1)
pcb | R5 | Resistor | 390 Ohm RC0603JR-07390RL | Yageo | RC0603JR-07390RL | C137632 |  | R_0603_1608Metric | 1 | 0.0010 | 0.0010 |  | qty=1000 estimate (~50% of LCSC qty=1)
pcb | C8+C13 | Capacitor | 100 pF CL10C101JB8NNNC | Samsung | CL10C101JB8NNNC | C14858 |  | C_0603_1608Metric | 2 | 0.0035 | 0.0035 |  | Photodiode AC-couple | qty=1000 = qty=1 (LCSC Basic; no volume tier)
pcb | R13+R15 | Resistor | 3.3 kOhm 0603WAF3301T5E | Uniroyal | 0603WAF3301T5E | C22978 |  | R_0603_1608Metric | 2 | 0.0009 | 0.0009 |  | Photodiode pull-up | qty=1000 = qty=1 (LCSC Basic; no volume tier)
pcb | C15 | Capacitor | 4.7 uF CL10A475KO8NNNC | Samsung | CL10A475KO8NNNC | C19666 |  | C_0603_1608Metric | 1 | 0.0087 | 0.0087 |  | qty=1000 = qty=1 (LCSC Basic; no volume tier)
pcb | Q1+Q2+Q4 | Transistor | 2N7002 N-MOSFET | onsemi | 2N7002 | C8545 |  | SOT-23 | 3 | 0.0127 | 0.0127 |  | IR LED drivers + buzzer | qty=1000 = qty=1 (LCSC Basic; no volume tier)
pcb | C6+C7 | Capacitor | 20 pF CL10C200JB8NNNC LSE load | Samsung | CL10C200JB8NNNC | C1648 |  | C_0603_1608Metric | 2 | 0.0046 | 0.0046 |  | qty=1000 = qty=1 (LCSC Basic; no volume tier)
pcb | R1+R3+R4+R7+R14+R16+R18 | Resistor | 100 Ohm 0603WAF1000T5E | Uniroyal | 0603WAF1000T5E | C22775 |  | R_0603_1608Metric | 7 | 0.0009 | 0.0009 |  | Gate series + current limit | qty=1000 = qty=1 (LCSC Basic; no volume tier)
pcb | R17 | Resistor | 1.8 kOhm 0603WAF1801T5E | Uniroyal | 0603WAF1801T5E | C4177 |  | R_0603_1608Metric | 1 | 0.0010 | 0.0010 |  | Buzzer pull-up | qty=1000 = qty=1 (LCSC Basic; no volume tier)
pcb | C4 | Capacitor | 22 uF CL10A226MQ8NRNC bulk | Samsung | CL10A226MQ8NRNC | C59461 |  | C_0603_1608Metric | 1 | 0.0082 | 0.0082 |  | qty=1000 = qty=1 (LCSC Basic; no volume tier)
pcb | C11+C16 | Capacitor | 1 uF CL10A105KB8NNNC | Samsung | CL10A105KB8NNNC | C15849 |  | C_0603_1608Metric | 2 | 0.0044 | 0.0044 |  | qty=1000 = qty=1 (LCSC Basic; no volume tier)
pcb | R11+R12+R19 | Resistor | 10 kOhm 0603WAF1002T5E | Uniroyal | 0603WAF1002T5E | C25804 |  | R_0603_1608Metric | 3 | 0.0008 | 0.0008 |  | SWD pulls + buzzer gate pull-down | qty=1000 = qty=1 (LCSC Basic; no volume tier)
pcb | R2+R6+R8+R10 | Resistor | 100 kOhm 0603WAF1003T5E | Uniroyal | 0603WAF1003T5E | C25803 |  | R_0603_1608Metric | 4 | 0.0009 | 0.0009 |  | Gate pull-down + battery divider | qty=1000 = qty=1 (LCSC Basic; no volume tier)
pcb | — | Fabrication | JLCPCB 50x45 mm 2-layer (qty=5 order $3.10 / 5) | JLCPCB |  |  |  |  | 1 | 0.62 | 0.30 |  | Y9-9959576A 2026-04-23 | qty=1000 estimate ($0.30/board at JLCPCB volume order)
satellite | D1+D2 | Photodiode | BPV10NF IR photodiode (TOP+BOT) | Vishay | BPV10NF | C118288 | 751-1002-ND |  | 2 | 0.6422 | 0.32 | https://www.vishay.com/docs/81502/bpv10nf.pdf | DigiKey CHF 0.578 each (2026-04-02 invoice) | qty=1000 estimate ~50% LCSC tier
satellite | LED1+LED2 | LED | VSLY5940 940 nm IR LED (TOP + BOT emitters) | Vishay | VSLY5940 |  | VSLY5940-ND |  | 2 | 0.9044 | 0.45 |  | DigiKey CHF 0.814 each (2026-04-02 invoice); SKU revised from VSMY2940RG (LCSC) to VSLY5940 (DigiKey actual)
satellite | — | Fabrication | Satellite breakout (FFC 6P→2.54mm adapter PCB) | AliExpress |  |  |  |  | 1 | 0.13 | 0.13 |  | CHF 0.12 flat at qty=1 and qty=1000 (AliExpress)
satellite | — | Optical bezel | IR LED + photodiode press-fit bezel | — |  |  |  |  | 4 | 0.046 | 0.046 |  | CHF 0.0415 each (CHF 165.93 / 4000)
mechanical | — | Cable | GCT 6-pin 0.5 mm FFC, 3.98 in (~10 cm) | GCT EMEA | 05-06-A-0101-A-4-06-4-T |  | 2073-05-06-A-0101-A-4-06-4-T-ND |  | 1 | 0.9000 | 0.40 |  | DigiKey CHF 0.81 each (2026-04-02 invoice) | qty=1000 estimate ~half DigiKey list
mechanical | — | Battery | 1x AA 1.5V USB-C Li-ion (Alibaba generic) | — | USB-C 1.5V Li-ion AA |  |  |  | 1 | 2.83 | 1.07 |  | Alibaba: CHF 2.55 at MOQ=1 (Doublepow); CHF 0.96 at MOQ=1000 (Shenzhou range bottom)
mechanical | — | Battery holder | Single AA holder with leads | Keystone | 2462 |  |  |  | 1 | 1.10 | 0.50 |  | about CHF 1 per holder | qty=1000 estimate (bulk Keystone)
mechanical | — | Filament | ASA white FDM (~25 g/device) | — |  |  |  |  | 1 | 0.75 | 0.65 |  | 1kg spool ~30 USD; 25 g per device = 0.75 USD | qty=1000 estimate (slight bulk filament discount)
mechanical | — | Filament | ASA black FDM (~5 g/device) | — |  |  |  |  | 1 | 0.15 | 0.13 |  | 1kg spool ~30 USD; 5 g per device = 0.15 USD | qty=1000 estimate (slight bulk filament discount)

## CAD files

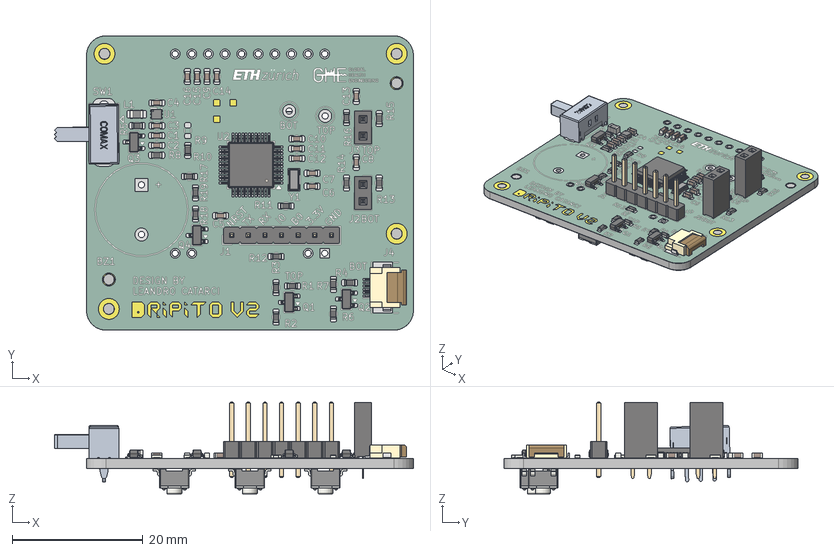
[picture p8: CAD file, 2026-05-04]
hardware/3dmodels/PCB/flow_monitor_full.step
54.9 x 45.0 x 14.0 mm
C_0603_1608Metric x 16
R_0603_1608Metric x 18
L_0805_2012Metric
SOT-23 x 4
TPS61098DSET
PinHeader_1x07_P2.54mm_Vertical
PinSocket_1x02_P2.54mm_Vertical x 2
SK-12D07-G 5 NS PA_PART1
LQFP-48_7x7mm_P0.5mm
Crystal_SMD_3215-2Pin_3.2x1.5mm
lock
pins
SW_SPST_PTS647Sx38 x 3
flow_monitor_copper
flow_monitor_pad
flow_monitor_via
flow_monitor_silkscreen x 2
flow_monitor_soldermask x 2
flow_monitor_PCB

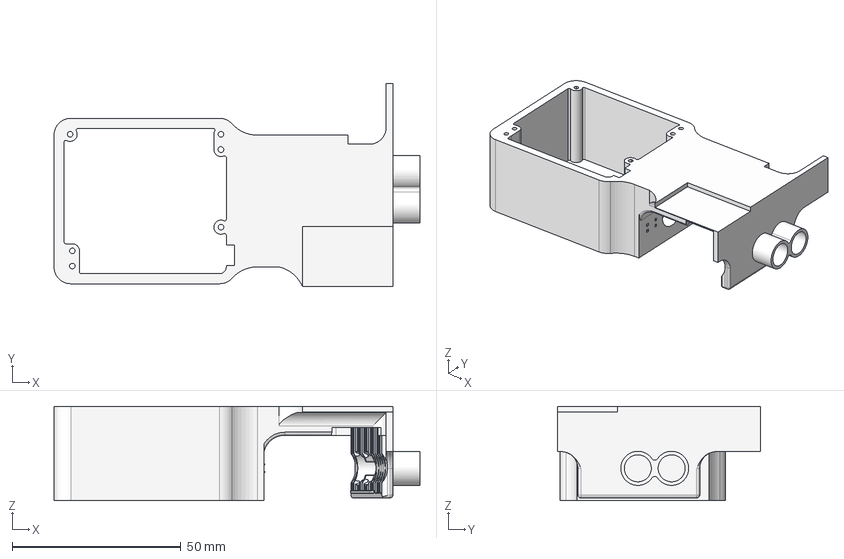
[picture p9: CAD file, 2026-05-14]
hardware/3dmodels/Enclosure/STEP/Back_Casing.step
108.3 x 60.0 x 27.9 mm

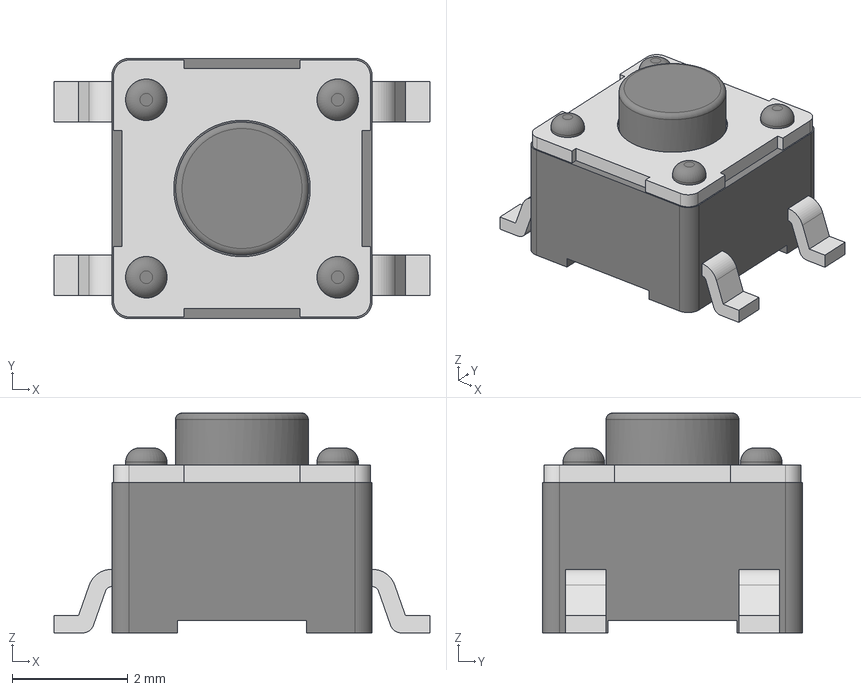
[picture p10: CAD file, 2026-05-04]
hardware/3dmodels/PCB/PTS647SN38SMTR2_LFS.stp
6.50 x 4.50 x 3.80 mm

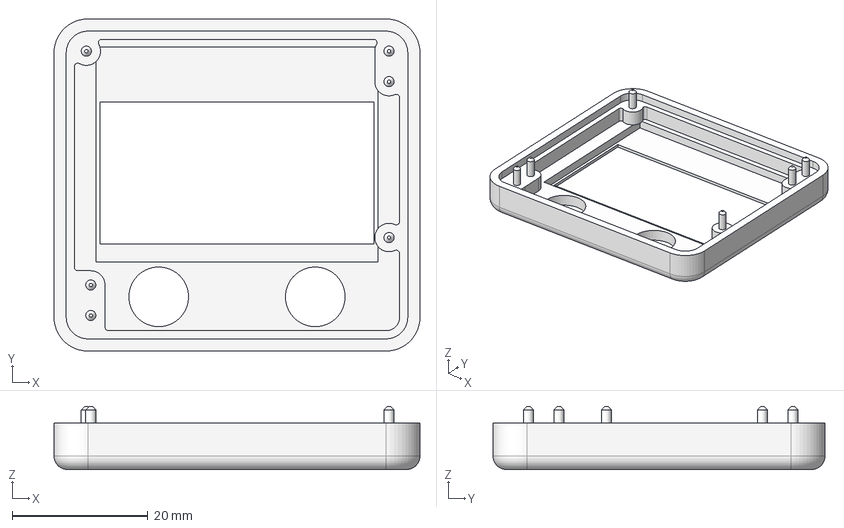
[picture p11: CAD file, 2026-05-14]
hardware/3dmodels/Enclosure/STEP/Front_Case.step
54.0 x 49.0 x 9.30 mm

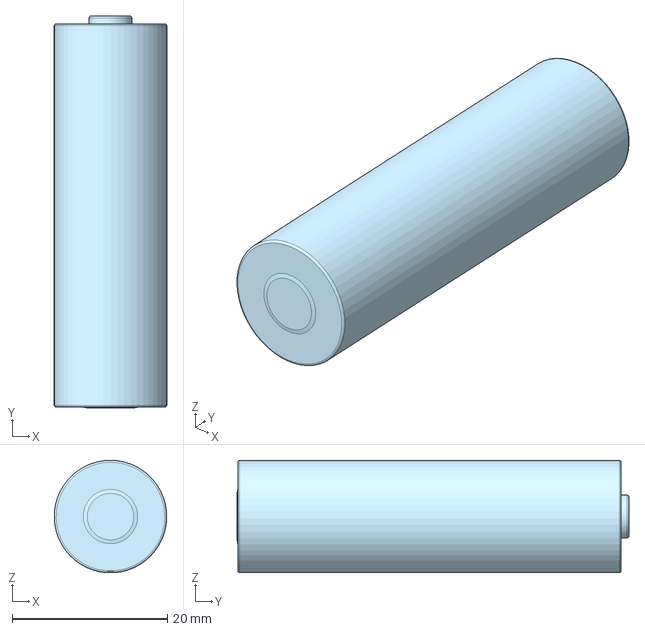
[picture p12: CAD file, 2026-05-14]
hardware/3dmodels/Enclosure/STEP/AA_Battery.step
14.5 x 50.5 x 14.5 mm

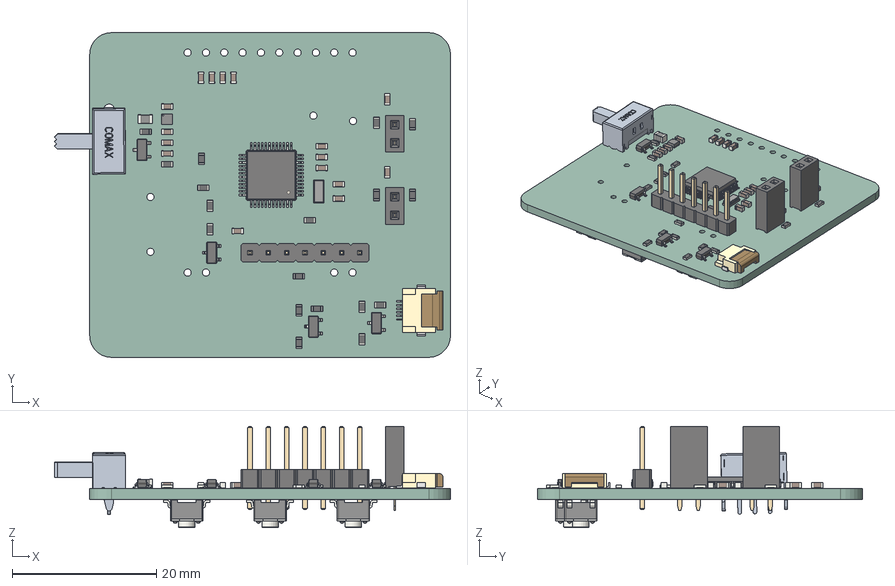
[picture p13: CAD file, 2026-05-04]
hardware/3dmodels/PCB/flow_monitor.step
54.9 x 45.0 x 14.0 mm
C_0603_1608Metric x 16
R_0603_1608Metric x 18
L_0805_2012Metric
SOT-23 x 4
TPS61098DSET
PinHeader_1x07_P2.54mm_Vertical
PinSocket_1x02_P2.54mm_Vertical x 2
SK-12D07-G 5 NS PA_PART1
LQFP-48_7x7mm_P0.5mm
Crystal_SMD_3215-2Pin_3.2x1.5mm
lock
pins
SW_SPST_PTS647Sx38 x 3
flow_monitor_PCB

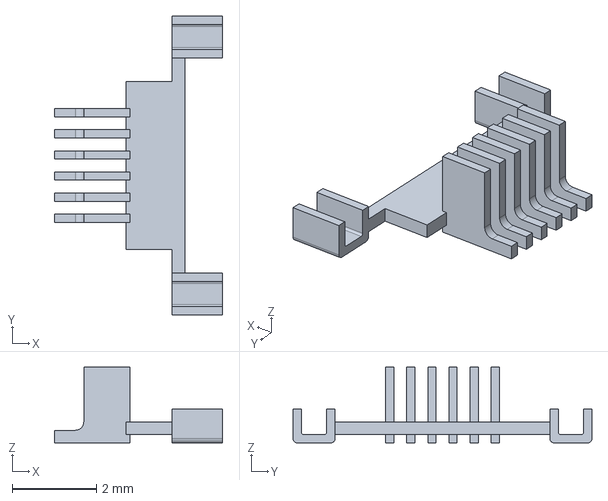
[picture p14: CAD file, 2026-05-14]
hardware/3dmodels/Enclosure/STEP/pins.step
4.00 x 7.10 x 1.80 mm

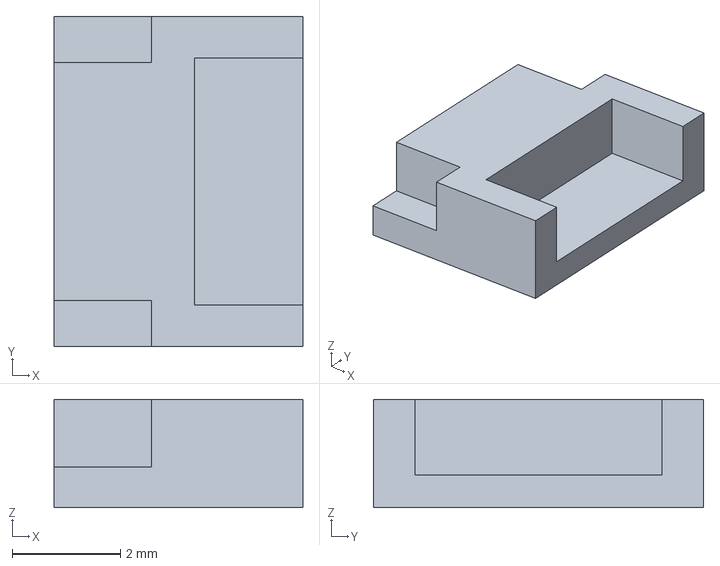
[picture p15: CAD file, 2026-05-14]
hardware/3dmodels/Enclosure/STEP/body.step
4.60 x 6.10 x 2.00 mm

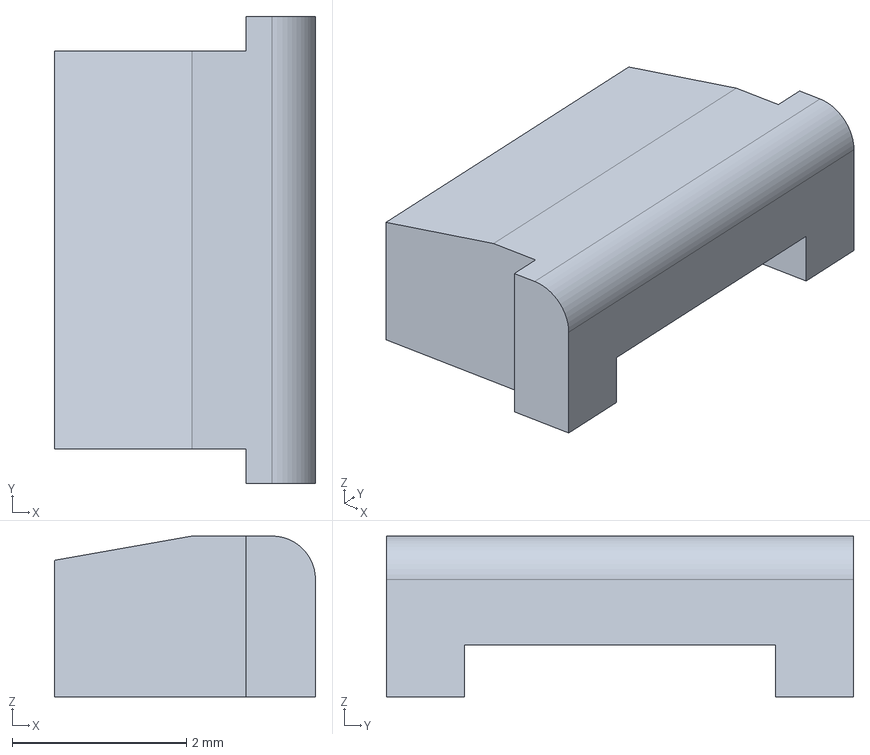
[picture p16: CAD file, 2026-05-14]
hardware/3dmodels/Enclosure/STEP/lock.step
3.00 x 5.37 x 1.85 mm

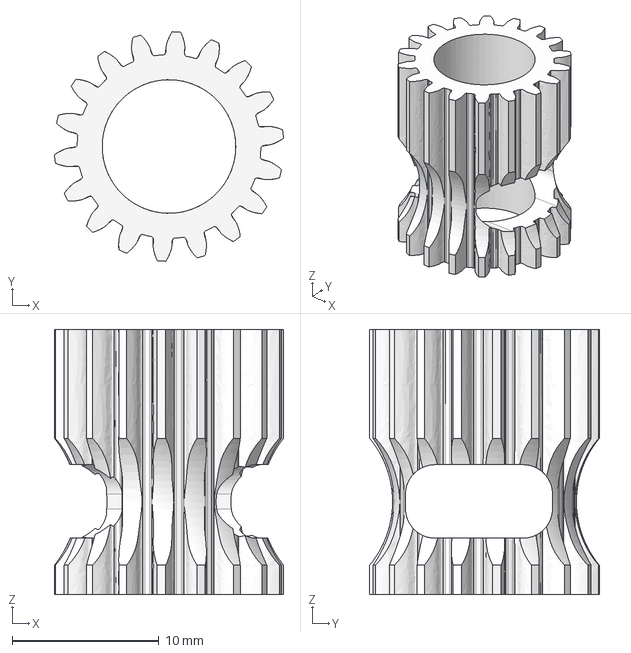
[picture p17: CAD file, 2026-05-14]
hardware/3dmodels/Enclosure/STEP/Gear.step
15.6 x 15.6 x 18.0 mm

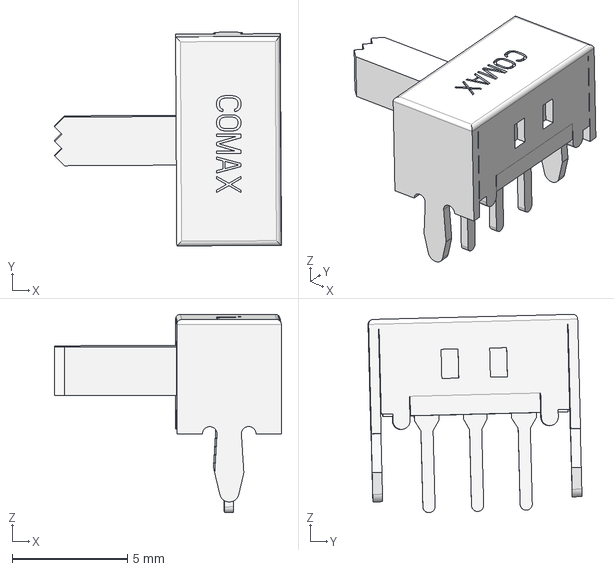
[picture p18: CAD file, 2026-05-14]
hardware/3dmodels/Enclosure/STEP/slide_switch.step
9.84 x 9.27 x 8.60 mm

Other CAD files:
hardware/3dmodels/Enclosure/STL/Back_Casing.stl
hardware/3dmodels/Enclosure/STL/Front_Case.stl
hardware/3dmodels/Enclosure/STL/Gear.stl

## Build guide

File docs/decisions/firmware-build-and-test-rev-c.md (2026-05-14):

# Firmware Build & Test — CubeIDE Only in Rev-B, Dockerized Build + Host-Side Tests Deferred to Rev-C

**Date:** 2026-05-14

## Context

Two related questions arose late in the Rev-B project about how the
firmware should be built and tested:

1. **Build tooling.** The firmware in
   `firmware/STM32CubeIDE/Dripito/` is generated by STM32CubeMX from
   the project's `.ioc` file and built by the STM32CubeIDE GUI. There is
   no CLI build wrapper, no Dockerized arm-none-eabi-gcc image, no
   reproducible-from-cold-clone firmware artefact. The analysis side of
   the repo runs end-to-end inside Docker
   (`docker compose up regenerate-figures-sample`); the firmware side
   does not.

2. **Host-side testing.** The drop-detection state machine in
   `main.c` is the safety-critical part of the device. It currently has
   one form of automated verification: `verify_estimator.py` (Monte
   Carlo against the drop-size math) runs in CI. The state machine
   itself — pulse-edge detection, threshold transitions, transit-time
   gating, V_CAL_K application — has no host-side unit test harness.

Both gaps were called out in the submission-day review as the only
realistic path to a 6.0 score on the rubric's 2R.4 (reproducibility) and
2R.5 (testing) sub-areas: "firmware host-side test… is the single
biggest 2R.5 lever," and "Dockerize firmware build — or honestly state
why not."

Both are also genuinely multi-hour pieces of work:

- A Dockerized firmware build means writing an `arm-none-eabi-gcc`
  Dockerfile, a `firmware/Makefile` that mirrors the CubeIDE-generated
  source tree, and reconciling the linker script and startup files
  without breaking the existing GUI build. Estimated 4–8 hours, with
  real risk of breaking the working bench-day firmware between submission
  and post-submission verification.

- A host-side state-machine test means extracting the drop-detection
  code into a target-agnostic translation unit, adding a Unity (or
  minimal) test harness, defining the pre-recorded RAW → DROP fixtures,
  and wiring it into CI. Estimated 4–6 hours.

Both estimates are too large for the submission-day window (2026-05-14),
which is committed to bench polish, documentation cleanup, and the demo.

## Decision

For Rev-B:

1. **Firmware build path is STM32CubeIDE GUI only.** No Dockerized build
   wrapper. The `.ioc` file is the source of truth for peripheral
   configuration; the CubeMX-generated source tree under
   `firmware/STM32CubeIDE/Dripito/Core/` is committed; building is
   *Project → Build All* in the IDE.

2. **No host-side unit tests for the drop-detection state machine.** The
   existing `verify_estimator.py` Monte-Carlo check of the volume math
   remains in CI; the state machine is verified indirectly through the
   bench dataset (V_50_01..05 captured in `data/raw/` and analysed in
   `analysis/notebooks/validation.ipynb`).

Both items are deferred to Rev-C with explicit scope below.

## Alternatives considered

- **Dockerized firmware build on submission day.** Lost on time budget
  and risk: the working bench-day firmware is the artefact the
  validation results depend on; breaking it 12 hours before submission
  to chase a rubric-bullet has worse expected value than naming the
  trade-off honestly.

- **Last-minute Unity harness for the state machine.** Same calculus —
  4–6 hours of refactoring against a tested-on-bench codebase, with
  meaningful regression risk. The bench dataset already exercises the
  state machine end-to-end; a unit test that re-replays the same RAW
  events would be additional evidence but is not a different *kind* of
  evidence in time for the deadline.

- **Quietly leave the gaps unstated.** Rejected because the rubric
  explicitly rewards justification of architectural trade-offs; an
  unjustified absence is graded as the worse posture.

## Consequences

- **Reproducibility (2R.4) is capped near 5.75.** A reader cloning the
  repo cannot rebuild the firmware artefact from a clean machine without
  installing STM32CubeIDE and following the GUI build steps. The
  analysis side of the repo is fully Dockerized and remains the
  cold-clone reproducibility surface.

- **Testing (2R.5) is capped near 5.75.** The drop-detection state
  machine is exercised in CI only via `verify_estimator.py` (math
  layer) and not via a host-side replay harness (logic layer). The
  bench dataset stays in `data/raw/` as the primary verification
  artefact.

- **Submission-day risk to the bench-validated firmware is zero.** The
  artefact that produced the V_50 results is the artefact that ships.

- **Rev-C scope is explicit.** Both items below are first-class
  deliverables of the next revision, not vague "future work":

  - `firmware/Dockerfile` with pinned `arm-none-eabi-gcc` and a
    `firmware/Makefile` that builds `Dripito.elf` from the
    CubeMX-generated sources.
  - `firmware/tests/` with a host-buildable harness around the
    drop-detection state machine, pre-recorded RAW fixtures replayed
    against the state machine in CI.

## Revisit triggers

- Rev-C kick-off — both deferred items move to in-scope.
- If a peer (or supervisor) provides a Dockerized arm-none-eabi build
  template that integrates cleanly with the CubeIDE-managed source
  tree without restructuring, the build half of this decision can be
  pulled forward without the time-budget risk above.
- If a regression in firmware behaviour is suspected between Rev-B
  submission and Rev-C kick-off, the host-side harness becomes
  priority-1 rather than priority-N to localise the cause.

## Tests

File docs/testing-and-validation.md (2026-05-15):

# Testing and Validation — Dripito Rev-B

The validation campaign as it actually ran. The pre-bench protocol document
(EXP-0 → EXP-6 across multiple days) is preserved in this repo's git
history and was compressed into a single bench day. This file documents
what the device was tested against, what was measured, and what was
deliberately left out of scope. Numerical results live in
[`results.md`](results.md); honest weaknesses ranked by impact live in
[`limitations.md`](limitations.md).

## Bench day — 2026-05-13

| Field | Value |
|---|---|
| Date | 2026-05-13 |
| Location | ETH GHE lab, light-controlled |
| Board | 1 (only) |
| Drip set | Macro 20 gtt/mL nominal |
| Fluid | Water, ρ = 1.000 g/mL |
| Beam separation | 10.2 mm (`../data/geometry.json`) |
| Power supply | 3.3 V via ST-Link debugger (boost chain bypassed) |
| Firmware constants (final, applied to all runs) | `BEAM_WIDTH_MM=0.0`, `CAL_MARGIN_HIGH=100`, `CAL_MARGIN_LOW=30`, `D_MM_MIN=0.1`, `V_CAL_K=1.27` |
| Ground truth | Mettler-Toledo MS-series precision scale (±0.0001 g) streaming SICS `SIR` at ~23 Hz |

The firmware constants above are the **final** values committed to
`firmware/STM32CubeIDE/Dripito/`. Constants were tuned during the
morning calibration runs (V_50_01..04); the calibrated value
`V_CAL_K = 1.27` was baked in and verified against the independent run
V_50_05. The full in-bench change log is in `limitations.md` §14.

## Ground truth — per-run chamber-orifice gravimetric

The device counts drops at the **drip-chamber orifice** (where they form).
The scale captures mass at the **end-of-tubing orifice** (where they fall
into the catch vessel). These two orifices have different geometry, so
they drip at different rates with different drop sizes — see
`limitations.md` §2.

Mass conservation still holds:

```
N_chamber × V_chamber  =  N_end × V_end  =  total mass through tubing
```

so the **only valid pairing** between the device's per-drop output and
the scale at the per-drop level is the per-run average:

```
V_true_chamber  =  total_mass_g × 1000 / N_UART_chamber_drops   (µL/drop)
```

Per-drop matching of UART events to scale steps is preserved as an
exploratory diagnostic only (`tools/match_scale_drops.py`; the docstring
documents the invalidation).

## Morning — calibration + verification runs

Five 3–10 minute runs at a clamp setting nominally 50 mL/hr (actual flow
varied; ground truth anchors on the gravimetric, not the clamp). Each run
produced three files in `../data/raw/`:

```
2026-05-13_macro20_50mlh_<NN>_board1.csv           # firmware DROP rows (12-col UART)
2026-05-13_macro20_50mlh_<NN>_board1.log           # raw UART mirror (audit trail)
2026-05-13_macro20_50mlh_<NN>_board1_scale.csv     # scale SIR stream
```

Per-run notes:

| Run | Detail file |
|-----|---|
| V_50_01 | [`bench/2026-05-13_V_50_01.md`](bench/2026-05-13_V_50_01.md) |
| V_50_02 | [`bench/2026-05-13_V_50_02.md`](bench/2026-05-13_V_50_02.md) |
| V_50_03 | [`bench/2026-05-13_V_50_03.md`](bench/2026-05-13_V_50_03.md) |
| V_50_04 | [`bench/2026-05-13_V_50_04.md`](bench/2026-05-13_V_50_04.md) |
| V_50_05 | [`bench/2026-05-13_V_50_05.md`](bench/2026-05-13_V_50_05.md) |
| V_streaming | [`bench/2026-05-13_V_streaming.md`](bench/2026-05-13_V_streaming.md) |

Headline numbers (per-run V_true_chamber, V_est, k_post, residuals) are
tabulated in [`results.md`](results.md). The summary: after applying
`V_CAL_K = 1.27`, the device tracks the gravimetric per-chamber-drop
average to within ±30 % across the operating envelope.

`V_CAL_K = 1.27` is the unweighted mean of `k_pre` across V_50_01..04
(see `results.md` for the derivation table). Reporting per-run residual
against the same four runs is a self-consistency check, not an
independent validation. V_50_05 — captured after baking `V_CAL_K` into
firmware — is the independent verification.

## Afternoon — mount-height re-test (position-drift)

A second session on the afternoon of 2026-05-13 mounted the device at
four mount positions on the same drip chamber, same drip set, same
fluid, same board, and measured the K required to make the LCD-summed
drop volume match the gravimetric reading at that position.

**Finding: for the shipped mean-of-pulses algorithm, K_fit varied from
0.42 to 1.27 across positions (3× spread). Across all eight algorithm
variants trialled in the afternoon, K_fit spanned 0.42 to 1.98 (4.7×
spread driven by mount geometry alone).** Three position-dependent
contaminants of the chord measurement were isolated (umbilical at TOP,
backsplash at BOT, threshold-vs-peak mismatch at the dual-threshold core
pulse). No single (algorithm, K) combination passed ±5 % at all
positions.

Full architectural analysis: `limitations.md` §17.

Raw afternoon runs live in `../data/raw/2026-05-13_pm_position_drift/`
with a per-run README inside the folder documenting each mount position
and the K required.

The Rev-B firmware was reverted to the morning-calibrated
`V_CAL_K = 1.27` mean-pulse state at the end of the afternoon session.
The position-dependence finding is documented as a §17 architectural
limit; the V_50 headline in `results.md` is left untouched.

## What was deliberately not in scope

| Out of scope (Rev-B) | Why | Where it's named |
|---|-----|---|
| Rev-A baseline (count-only firmware) | Earlier InfusionBA was removed in commit `ed84ff5`; recovering it for a head-to-head was infeasible in the project timeline | `limitations.md` §12 |
| Multiple drip sets | Single macro 20 gtt/mL available on bench | `limitations.md` §10 |
| Multiple boards | Single board built; board-to-board scatter from the printed sensor arm is un-quantified | `limitations.md` §8, §16 |
| Multiple head heights | Single head height; clinical range 60–150 cm not covered | `limitations.md` §13 |
| Battery-powered runs | Tethered 3.3 V via ST-Link; TPS610981 boost chain not in the validated loop | `limitations.md` §7 |
| Multi-session generalisation | Single bench day; drift across sessions un-quantified | `limitations.md` §15 |

## Data + analysis cross-links

- Raw CSVs: `../data/raw/` — see [`../data/README.md`](../data/README.md) for column schemas.
- Per-run gravimetric summary: `../data/gravimetric_log.csv`.
- Geometry: `../data/geometry.json`.
- Analysis pipeline: [`../analysis/`](../analysis/) — `docker compose up regenerate-figures-sample` regenerates the headline figure from sample data.
- Headline results: [`results.md`](results.md).

## Archive / Zenodo

The complete dataset (raw CSVs, gravimetric log, per-drop summaries,
analysis pipeline) is deposited on Zenodo under CC BY 4.0. DOI:
[10.5281/zenodo.20199232](https://doi.org/10.5281/zenodo.20199232).

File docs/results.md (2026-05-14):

# Results

Validation of the Rev-B dual-beam drop-volume monitor against gravimetric ground truth, 2026-05-13. Four 10-minute calibration runs (V_50_01..04), one independent-verification run (V_50_05, captured **after** baking V_CAL_K into firmware), and one streaming-regime sample (`V_streaming`) characterise the device's behaviour across a 39–186 µL chamber-drop range. A separate afternoon position-drift session (11 runs across four mount positions) and a 2026-05-14 raw-waveform session (3 gravimetric-paired captures) extend the analysis — see [`limitations.md`](limitations.md) §17 and the Pages site's Analysis section respectively.

Headline finding: **after applying a single scalar correction `V_CAL_K = 1.27`, the device's per-run mean volume tracks gravimetric ground truth to within ±30 % across the four calibration runs (V_50_01..04); the holdout run V_50_05 confirms the constant generalises (k_post = 1.24, inside the [0.79, 1.27] calibration bracket)**. A ±30 % per-run spread is far outside any clinical accuracy target; Rev-B is a working dual-beam architecture demonstrator, not a clinically deployable monitor. Residual error sources are inventoried in [`limitations.md`](limitations.md).

## Bench dataset

| Field | Value |
|---|---|
| Date | 2026-05-13 |
| Drip set | nominal macro 20 gtt/mL (see `docs/limitations.md`) |
| Fluid | Water, ρ = 1.000 g/mL |
| Beam separation | 10.2 mm (`data/geometry.json`) |
| Runs | V_50_01, V_50_02, V_50_03, V_50_04 (with caveat); V_50_05 (holdout — captured after firmware V_CAL_K was set from V_50_01..04); plus V_streaming sample (continuous-flow regime, documented separately in `docs/bench/2026-05-13_V_streaming.md`) |
| Firmware constants | `BEAM_WIDTH_MM=0.0`, `CAL_MARGIN_HIGH=100`, `CAL_MARGIN_LOW=30`, `D_MM_MIN=0.1`, `V_CAL_K=1.27` |

Each run records two side-channel streams in parallel:
- Firmware DROP rows over UART (12-column CSV; `data/raw/*.csv`)
- Mettler-Toledo MS scale via SICS `SIR` at ~23 Hz (`data/raw/*_scale.csv`)

## Ground-truth definition

Per-drop ground truth is the per-run **chamber-orifice** gravimetric average:

```
V_true_chamber = total_mass_g × 1000 / N_UART_chamber_drops   (µL per chamber drop)
```

This is the only valid pairing between the device measurement and the scale at the per-drop level. The scale captures mass at the **end-of-tubing orifice**, which has different geometry than the chamber orifice and drips at a different rate (see `docs/limitations.md` §Two-orifice divergence). Mass conservation gives:

```
N_chamber × V_chamber = N_end × V_end = total mass
```

so total mass is a clean shared quantity, but `N_chamber ≠ N_end`. The 2026-05-13 campaign typically saw end-orifice drop counts 1.5–2× the chamber-drop counts. Per-drop matching of UART events to scale steps is preserved only as an exploratory diagnostic (`tools/match_scale_drops.py`).

In clinical use the two-orifice gap collapses: with a catheter in a vein, the fluid column is closed at the patient end and the chamber-drop count equals the volume actually delivered. The divergence is a bench-measurement artefact of dripping into open air, not a clinical-accuracy concern.

## Per-run summary

All `V_est` figures below come from `load_run.py`, which mirrors the firmware physics exactly: gravity-corrected `v_TOP = L/dt − ½g·dt`, mean-of-pulses chord time, sphere-volume conversion, then the `V_CAL_K = 1.27` scalar. The uncalibrated chord-sphere number is `V_est_calibrated / 1.27`.

| Run | Duration (s) | N drops | Mass (g) | Grav flow (mL/h) | V_true_chamber (µL) | V_est_calibrated (µL) | k_post = V_true / V_est | Direction |
|---|---:|---:|---:|---:|---:|---:|---:|---|
| V_50_01 | 185.6 | 65 | 4.7992 | 93.09 | 73.83 | 58.35 | 1.27 | device under |
| V_50_02 | 573.5 | 339 | 13.3097 | 83.55 | 39.26 | 49.84 | 0.79 | device over |
| V_50_03 | 600.0 | 180 | 10.6780 | 64.07 | 59.32 | 57.29 | 1.04 | within noise |
| V_50_04 | 600.0 | 40 (gap) | 7.4441 | 44.66 | ≤186.10 | 208.44 | ≥0.89 | exploratory |
| V_50_05 | 599.7 | 153 | 7.9481 | 47.72 | 51.76 | 41.59 | 1.24 | **holdout — device under** |
| V_streaming | 141 | 66 | — | ≈ 269 | — | range 0.3–183 µL (regime breakdown) | — | streaming regime |

mean(k_post) across V_50_01..04 = 0.995 (well within rounding of 1.0, as expected since `V_CAL_K` is the mean of these four runs' `k_pre`). Worst-case per-run deviation is V_50_01 (1.27×, device under-reads by 21%) and V_50_02 (0.79×, device over-reads by 27%). The k_post spread of 0.79–1.27 is the ±30 % residual referenced in the headline.

V_50_05 was captured **after** `V_CAL_K = 1.27` was committed to firmware, so its `k_post = 1.24` is the first independent generalisation check rather than another self-consistency point. The value falls inside the [0.79, 1.27] calibration bracket from V_50_01..04 — `V_CAL_K` is not over-fit to the calibration set, but the per-drop residual structure (drop-shape oscillation, [`limitations.md`](limitations.md) §1) is unchanged. Detail: [`docs/bench/2026-05-13_V_50_05.md`](bench/2026-05-13_V_50_05.md).

Detail per run: `docs/bench/2026-05-13_V_50_0{1,2,3,4,5}.md` and `docs/bench/2026-05-13_V_streaming.md`.

## How `V_CAL_K` was chosen

`V_CAL_K = 1.27` is the unweighted mean of the per-run `k_pre = V_true_chamber / V_est_uncalibrated` values across V_50_01..04 (gravity-corrected mean-pulse model):

| Run | V_true_chamber (µL) | V_est_uncalibrated (µL) | k_pre |
|---|---:|---:|---:|
| V_50_01 | 73.83 | 45.95 | 1.607 |
| V_50_02 | 39.26 | 39.24 | 1.001 |
| V_50_03 | 59.32 | 45.11 | 1.315 |
| V_50_04 | 186.10 | 164.13 | 1.134 |
| **Mean** | | | **1.264** |

Rounded to two decimals → `V_CAL_K = 1.27`. The firmware applies this constant inside the volume calculation in `main.c`; the offline `analysis/scripts/load_run.py` carries the same constant for byte-identical numbers between bench-time LCD output and post-hoc analysis.

Mass-weighted (1.21) and drop-count-weighted (1.17) averages give close but different values; the choice of unweighted mean was deliberate, so that the slow-drip regime (V_50_04, large drops, fewer drops, small mass) gets equal say as the fast-drip regime (V_50_02, small drops, many drops, large mass). The ±30 % residual is the same to first order under any of the three weightings.

## Architecture findings — 2026-05-13 bench

### 1. TOP/BOT optical-channel asymmetry

The two photodiodes report systematically different pulse widths for the same physical drop. Across V_50_01..04 at the original device position with `CAL_MARGIN_HIGH=100`:

| Run | pulse_TOP median (µs) | pulse_BOT median (µs) | BOT/TOP ratio | Physics-expected ratio |
|---|---:|---:|---:|---:|
| V_50_01 | 3896 | 8076 | 2.09× | 0.92× |
| V_50_02 | 3190 | 8013 | 2.50× | 0.92× |
| V_50_03 | 3124 | 5834 | 1.87× | 0.92× |
| V_50_04 | 4680 | 8163 | 1.75× | 0.92× |

The physics prediction comes from gravity acceleration over the 10 mm beam pitch: the drop is travelling ~9 % faster at BOT than at TOP, so its chord-time at BOT should be 9 % **shorter** than at TOP. Bench shows BOT pulses 75–150 % **longer** than TOP. The mean-of-pulses approach in firmware partially absorbs this (BOT over, TOP under → mean roughly tracks truth), but the residual mismatch is one of two drivers of the ±30 % per-run k variance.

### 2. The BOT extension is partially backsplash, partially intrinsic

Falsifiable test on-bench (2026-05-13, ~16:00): the device was repositioned ~3 cm higher on the drip chamber so the BOT beam was further from the pool surface. At the higher position and original thresholds, **the BOT/TOP ratio fell from ~2.0× to ~1.13×** — much closer to physics-expected 0.92×. With thresholds lowered to `CAL_MARGIN_HIGH=30` at the same higher position, the ratio jumped to ~7.8× as the lower threshold caught a long BOT tail invisible at margin=100.

Interpretation: the BOT photodiode sees a real splash-driven tail that the margin=100 threshold clips. Moving the BOT beam further from the pool reduces the tail. Some residual TOP/BOT mismatch persists even at the higher position (1.13× vs 0.92×), so the sensor itself has a small intrinsic asymmetry on top of the backsplash effect.

The current firmware keeps `CAL_MARGIN_HIGH=100` to clip the splash artefact, accepting the residual ~1.2× ratio. A Rev-C optical front-end with the BOT beam moved further from the pool, plus TOP/BOT gain equalisation, would close the gap.

## Drop counting is reliable inside the operating envelope

Inter-drop interval analysis across V_50_01..03 shows tight distributions (p90 < 1.05× median interval), so **the firmware is not missing or doubling chamber drops** in normal flow regimes. The drop **count** is a defensible quantity; only the per-drop volume carries the ±30 % uncertainty.

| Run | Median interval (s) | p90 interval (s) | Gaps > 2× median |
|---|---:|---:|---:|
| V_50_01 | 2.06 | 2.13 | 1 (44.5 s — real drip pause) |
| V_50_02 | 1.63 | 1.72 | 1 (3.4 s — flow micro-stall) |
| V_50_03 | 2.95 | 3.08 | 2 (46.7 s reflash gap; 4.5 s) |

V_50_04 is exempt from this conclusion — it has 15 intervals exceeding 2× the median, including the 248 s mid-run gap.

## Reproducibility

The full chain regenerates byte-identically from a fresh clone:

```powershell
# Acquire bench data (one-time, requires hardware)
python tools\log_uart_run.py capture --port COM3 --rate 50 --run 01 --duration 200 --force
python tools\log_scale.py --port COM4 stream --duration 200 `
  --out data\raw\2026-05-13_macro20_50mlh_01_board1_scale.csv

# Build the overlay figure and the cross-run summary
python tools\build_bench_overlay.py `
  --device-csv data\raw\2026-05-13_macro20_50mlh_01_board1.csv `
  --scale-csv  data\raw\2026-05-13_macro20_50mlh_01_board1_scale.csv `
  --beam-mm 10.2 --density 1.000 --rate-mlh 50

# Sanity-check the firmware k against the offline model
python -c "from analysis.scripts.load_run import load_run, V_CAL_K, summarise_run; print(V_CAL_K)"
```

`analysis/figures/bench_overlay_summary.csv` is the cross-run artefact. Per-run bench notes are in `docs/bench/2026-05-13_V_50_0*.md`. Full limitation inventory in `docs/limitations.md`.

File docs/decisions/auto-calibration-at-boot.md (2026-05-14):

# Threshold Auto-Calibration at Boot

**Date:** 2026-05-04 (architecture); finalised as primary path during 2026-05-13 campaign

## Context

The Rev-B [optical front-end](optical-architecture.md) uses internal COMP1 thresholded against a DAC reference to detect drop events. The threshold value depends on (a) the baseline illumination delivered by the IR LED to each photodiode in the assembled device, and (b) the drop-shadow depth, which depends on chamber OD, fluid optical properties, and beam alignment. These quantities vary across boards (FDM tolerance, see [`sensor-arm-alignment.md`](sensor-arm-alignment.md)), across drip-set / fluid combinations, and across ambient illumination conditions. A fixed compile-time threshold cannot stay correct across this variation; some form of per-boot adaptation is needed.

## Decision

The firmware **auto-calibrates the COMP1 detection thresholds at every boot** by sweeping the IR LEDs against the photodiode baseline, measuring the baseline and the in-shadow minimum, and computing per-beam threshold values from that pair. No compile-time `#define` threshold is retained as a fallback — auto-cal is the **sole** threshold source in Rev-B.

The auto-cal output (baseline, in-shadow minimum, computed threshold per beam, timestamp, board ID) is streamed over UART and written to `data/calibration_log.csv` for every session so threshold history is reproducible from the data record.

## Alternatives considered

- **Pure manual hard-coded `#define` thresholds (no auto-cal).** Rejected: cannot stay correct across board-to-board variation, drip-set changes, or ambient illumination changes without manual recompile. Reproducibility-of-data argument that originally favoured this path (fixed threshold = no per-boot drift) is outweighed by the operational fragility — a fixed threshold gives the wrong answer the moment the device is moved or the chamber changes.
- **Hybrid (auto-cal as primary, `#define` as fallback if auto-cal sanity check fails).** Was the architecture proposed in the 2026-05-04 planning note. Rejected for Rev-B because it doubles the firmware paths the validation campaign has to characterise; the auto-cal path can be made robust enough on its own, and a fallback would mask auto-cal failures during validation. The fallback path is reintroducible in Rev-C if auto-cal proves unreliable in field deployment.
- **Per-session manual recalibration triggered by the user.** Rejected on UX grounds: clinicians should not be expected to perform a calibration step before each use. The boot-time auto-cal is the per-session calibration.

## Consequences

- **Per-board, per-session adaptive thresholds.** The device adapts to its own LED current, photodiode placement, sensor-arm geometry, and ambient illumination on every boot, without any user input.
- **Threshold history is in the data record.** Every session's auto-cal output is logged to `calibration_log.csv`. The validation analysis (`docs/results.md`) can be cross-referenced against the per-session thresholds.
- **Silent auto-cal failure is a real risk.** If auto-cal converges on a bad threshold (misaligned beam, low LED current at boot, bubble in chamber during sweep, ambient light spike, threshold-vs-peak boot-cal drift — see [`../limitations.md`](../limitations.md) §Position-dependence), the device runs with incorrect thresholds and the run looks normal until post-hoc analysis catches it. Bench evidence from the 2026-05-13 campaign shows this happens — the boot-cal baseline shifts 100–200 counts between sessions and the fixed-margin core threshold cuts at a different fraction of (peak − baseline) per boot, contributing to the per-run residual.
- **No `#define` rescue path if auto-cal breaks.** A firmware build with a fundamental auto-cal bug bricks the device for the user. Mitigation in Rev-B is to surface auto-cal output via UART so a failure is observable on-bench; not a user-facing mitigation.

## Revisit triggers

- If field deployment shows auto-cal failure modes that cannot be made observable from inside the device (no UART, no logs accessible), reintroduce a `#define` fallback or add explicit on-LCD diagnostic output.
- If the boot-cal baseline drift documented in [`../limitations.md`](../limitations.md) §Position-dependence is shown to materially degrade accuracy and cannot be fixed by algorithm rework in the chord-time estimator, the auto-cal sanity-check criteria become a load-bearing part of the optical architecture and may need rework.
- If Rev-C uses a different optical front-end (e.g. analog continuous sampling, different photodiode), the entire calibration approach reopens.

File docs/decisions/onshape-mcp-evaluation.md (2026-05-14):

# Onshape MCP Evaluation — Not Adopted for Rev-B

**Date:** 2026-05-01

## Context

The community Onshape MCP server (`hedless/onshape-mcp`, v0.3.0, 2026-03-02) exposes Onshape's parametric CAD API through the Model Context Protocol so that LLM-based agents can read variable tables, create sketches and features, and export model formats. The mechanical work on Dripito's enclosure (sensor arm, front plate, chamber-holder geometry, mounting bosses, LCD cutout) is parametric in nature — drip-chamber OD, sensor-arm-to-PCB standoff, LED bezel diameter, button bore size — and would in principle benefit from automated variable-table iteration if the tooling were sufficient.

## Decision

**The Onshape MCP server was evaluated for Rev-B and not adopted.** The Rev-B enclosure was completed in Onshape directly via the GUI.

## Why not adopted

The Onshape MCP exposes 45 tools covering variable-table read/write, parametric sketch and feature creation (rectangles, circles, lines, arcs, extrude, revolve, fillet, chamfer, boolean operations, linear and circular patterns), assembly mate creation, and STL/STEP/PARASOLID/GLTF/OBJ export. Sufficient on paper for the kind of variable-driven enclosure tweaks anticipated for Rev-C and beyond. Two limitations made it unsuitable for the current revision:

1. **Sketch constraints (coincident, parallel, horizontal/vertical) are not exposed.** Geometry placed via the MCP is not robustly constrained against variable changes — a downstream variable update can break the geometry rather than driving it. For parametric work this is the key feature that's missing.
2. **Sketches can only be created on the three standard planes.** Not on existing feature faces. This forecloses the mounting-boss, LCD-cutout, and arm-clamp work that dominates enclosure iteration — most real CAD work places sketches on faces of already-extruded features.

Combined with the setup cost (Onshape API credential provisioning, document-tree learning) and the Rev-B enclosure deadline already slipped to 2026-04-30, the cost/benefit was negative.

## Alternatives considered

- **Adopt the MCP now for Rev-B parametric work.** Rejected on the two functional gaps above plus the schedule cost at the wrong moment in the sprint.
- **Skip the evaluation entirely.** Rejected: knowing whether parametric agent-driven CAD is viable for Dripito's enclosure work is a Rev-C-relevant question and the evaluation itself is cheap once the tool's tools list is read.

## Consequences

- **Rev-B enclosure work was completed in the Onshape GUI by hand.** No automation overhead; no novel failure modes from agent-driven CAD.
- **The evaluation note exists for the next iteration.** A Rev-C author considering parametric CAD has a documented reading of where the upstream tool stands as of 2026-05-01.

## Revisit triggers

- If sketch-on-face support lands upstream in `hedless/onshape-mcp` (or an equivalent tool), the central blocker is removed and the cost/benefit shifts.
- If a sensitivity study across wall-thickness / material variants becomes part of the Rev-C analysis, variable-table iteration plus scripted STL export would pay back the setup cost.
- If Onshape itself ships first-party MCP / agent support with full sketch-constraint coverage, this evaluation is superseded.

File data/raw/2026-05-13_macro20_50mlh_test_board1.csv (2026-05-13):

abs_ms | drop_N | transit_us | pulse_top_us | pulse_bot_us | v_cmps | d_0.1mm | V_0.1uL | state | Q_cmLph | top_raw | bot_raw
139115 | 21 | 11155 | 3633 | 7237 | 84 | 47 | 551 | 2 | 0 | 3690 | 3418
142758 | 22 | 11164 | 3724 | 7228 | 84 | 48 | 562 | 2 | 158 | 3695 | 3419
146377 | 23 | 11170 | 3766 | 7203 | 84 | 48 | 564 | 2 | 316 | 3682 | 3417
150011 | 24 | 11224 | 3763 | 7160 | 84 | 47 | 547 | 2 | 474 | 3702 | 3424

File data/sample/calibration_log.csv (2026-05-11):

date | board_id | mode | thresh_top | thresh_bot | baseline_top_mean | baseline_bot_mean | false_pos_60s | notes
2026-05-13 | board1 | manual | 2400 | 2350 | 3105 | 3092 | 0 | sample EXP-0 calibration

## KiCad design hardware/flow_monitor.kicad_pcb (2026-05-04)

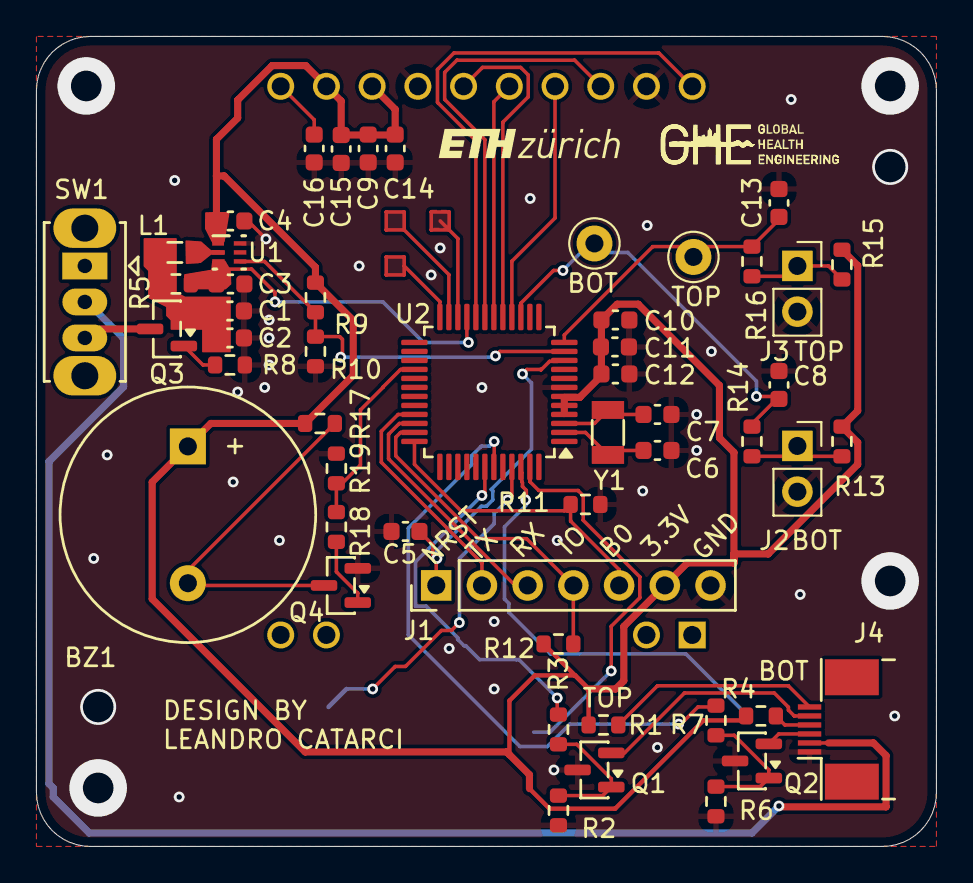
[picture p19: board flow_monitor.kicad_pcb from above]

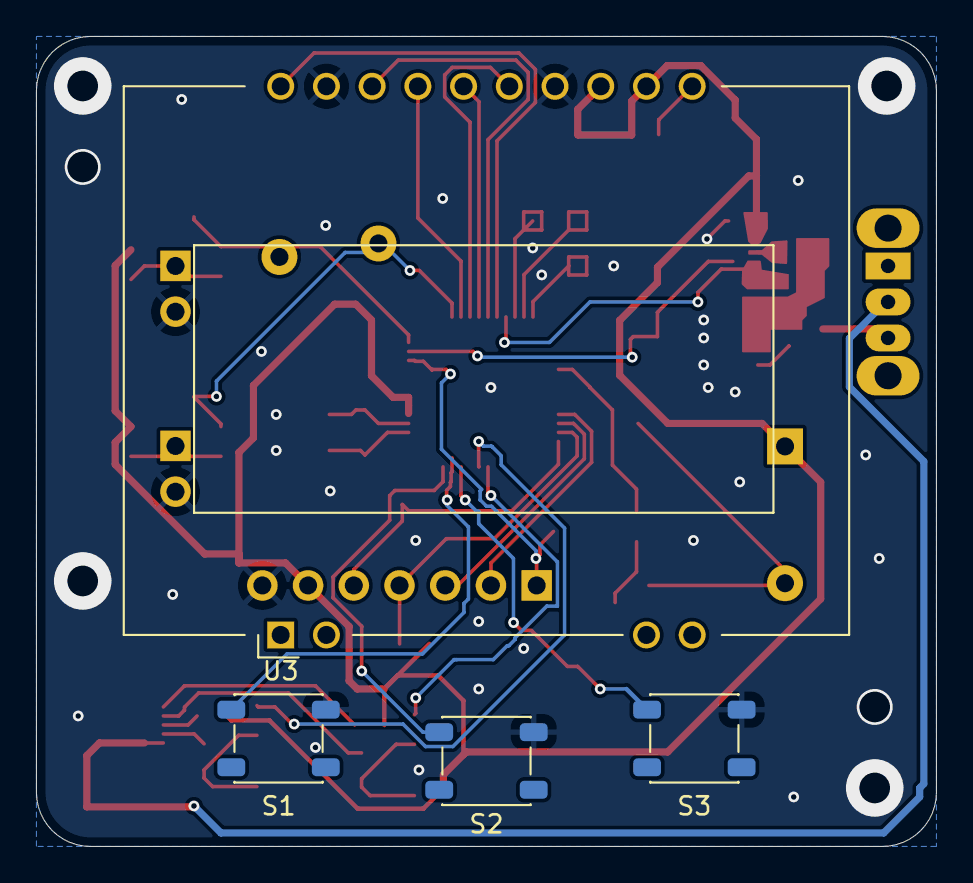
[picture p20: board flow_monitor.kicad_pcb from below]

Board: 2 copper layers, 50.0 x 45.0 mm, 55 parts (4 on the bottom side), 40 nets.

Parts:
BOT: TestPoint; TestPoint_Keystone_5000-5004_Miniature
BZ1: SFN-1407PA7.6; Buzzer_S&S_SFN-1407PA7.6
C1: 10uF; C_0603_1608Metric
C2, C3, C5, C14: 100nF; C_0603_1608Metric
C4: 22uF; C_0603_1608Metric
C6, C7: 20pF; C_0603_1608Metric
C8, C13: 100pF; C_0603_1608Metric
C9, C10, C12: 0.1uF; C_0603_1608Metric
C11: 1uF; C_0603_1608Metric
C15: 4700nF; C_0603_1608Metric
C16: 1000nF; C_0603_1608Metric
J1: Conn_01x07_Pin; PinHeader_1x07_P2.54mm_Vertical
J2: Conn_01x02_Socket_TOP; PinSocket_1x02_P2.54mm_Vertical
J3: Conn_01x02_Socket_BOT; PinSocket_1x02_P2.54mm_Vertical
J4: Conn_01x06_Socket; Jushuo_AFC07-S06FCA-00_1x6-1MP_P0.50_Horizontal
L1: 4.7uH; L_0805_2012Metric
Q1, Q2, Q4: 2N7002; SOT-23
Q3: AO3401A; SOT-23
R1, R3, R4, R7, R14, R16, R18: 100Ω; R_0603_1608Metric
R2, R6: 100kΩ; R_0603_1608Metric
R5: 390Ohm; R_0603_1608Metric
R8, R9, R10: 100k; R_0603_1608Metric
R11, R12, R19: 10kΩ; R_0603_1608Metric
R13, R15: 3.3kΩ; R_0603_1608Metric
R17: 1800Ω; R_0603_1608Metric
S1, S2, S3: PTS647SN38SMTR2_LFS; SW_SPST_PTS647_Sx38
SW1: SK12D07VG5; X_SW_Slide_SPDT_SSK12D07VG5
TP1: TestPoint; TestPoint_Keystone_5000-5004_Miniature
U1: TPS610981DSET; DSE0006A
U2: STM32G071C8Tx; LQFP-48_7x7mm_P0.5mm
U3: EA_DOGS164W-A; EA_DOGS164X-A
Y1: Crystal; Crystal_SMD_3215-2Pin_3.2x1.5mm

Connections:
+3.3V: BZ1.1 (+), C4.2, C9.1, C10.1, C11.2, C12.2, C14.1, C15.2, J1.6, R1.1, R4.1, R9.1, R12.1, R13.1, R15.1, R17.1, U1.1 (VMAIN), U2.4 (VBAT), U2.5 (VREF+), U2.6 (VDD), U3.12 (IM1), U3.13 (VDD)
/BUZZER_GATE: Q4.1 (G), R18.1
/LCD_VOUT: C16.2, U3.11 (VOUT)
/LED_GATE_BOT: Q2.1 (G), R6.2, R7.1
/LED_GATE_TOP: Q1.1 (G), R2.2, R3.1
/OSC32_IN: C6.2, U2.2 (PC14), Y1.2
/OSC32_OUT: C7.2, U2.3 (PC15), Y1.1
ADC_IR_DETECTOR_BOT: BOT.1, C8.2, R14.1, U2.15 (PA4)
ADC_IR_DETECTOR_TOP: C13.2, R16.1, TP1.1, U2.12 (PA1)
ADC_V_BAT: C3.2, R5.2, U1.3 (VIN), U2.21 (PB2)
BAT+: J4.2, SW1.2 (B)
BOOT0: J1.5, R11.1, U2.36 (PA14)
BST_MODE: R9.2, R10.1, U1.4 (MODE), U2.11 (PA0)
BST_SW: L1.2, U1.2 (SW)
BTN_MODE: S1.1 (NO), U2.46 (PB7)
BTN_MUTE: S3.1 (NO), U2.45 (PB6)
BTN_RES: S2.1 (NO), U2.47 (PB8)
BUZZER_CTRL: R18.2, R19.2, U2.28 (PA8)
BZ_DRN: BZ1.2 (-), Q4.3 (D), R17.2
GND: C1.2, C2.1, C3.1, C4.1, C5.2, C6.1, C7.1, C8.1, C9.2, C10.2, C11.1, C12.1, C13.1, C14.2, C15.1, C16.1, J1.7, J2.2, J3.2, J4.1, Q1.3 (D), Q2.3 (D), Q4.2 (S), R2.1, R6.1, R8.2, R10.2, R11.2, R19.1, S1.1 (NO), S2.1 (NO), S3.1 (NO), U1.6 (GND), U2.7 (VSS), U3.14 (VSS), U3.19 (SA0)
IR_LED_BOT+: J4.4, R4.2
IR_LED_BOT-: J4.3, Q2.2 (S)
IR_LED_TOP+: J4.6, R1.2
IR_LED_TOP-: J4.5, Q1.2 (S)
LCD_CS: U2.19 (PB0), U3.18 (CS)
LCD_MISO: U2.17 (PA6), U3.15 (SOD)
LCD_MOSI: U2.18 (PA7), U3.16 (SID)
LCD_RST: U2.20 (PB1), U3.20 (RST)
LCD_SCK: U2.16 (PA5), U3.17 (SCLK)
LED_CTRL_BOT: R7.2, U2.43 (PB4)
LED_CTRL_TOP: R3.2, U2.42 (PB3)
NRST: C5.1, J1.1, U2.10 (NRST)
PD_BIAS_BOT: J2.1, R13.2, R14.2
PD_BIAS_TOP: J3.1, R15.2, R16.2
RPOL_GATE: Q3.1 (G), R8.1
SWDIO: J1.4, R12.2, U2.35 (PA13)
UART1_RX: J1.3, U2.34 (PA10/PA12)
UART1_TX: J1.2, U2.33 (PA9/PA11)
VBAT_PROT: C1.1, C2.2, L1.1, Q3.2 (S), R5.1
VBAT_SW: Q3.3 (D), SW1.3 (C)

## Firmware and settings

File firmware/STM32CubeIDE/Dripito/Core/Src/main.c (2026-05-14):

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
/* Includes ------------------------------------------------------------------*/
#include "main.h"

/* USER CODE BEGIN Includes */
#include "lcd.h"
#include "buzzer.h"
#include "buttons.h"
#include <stdio.h>
#include <math.h>
#include <string.h>
/* USER CODE END Includes */

/* USER CODE BEGIN PD */
/* Phase 1 dual-beam drop-detection demo */
#define BEAM_PITCH_MM     10.0f       /* TOP-to-BOT optical centre-to-centre */
#define G_MMPS2           9810.0f     /* gravitational acceleration, mm/s^2  */
#define BEAM_WIDTH_MM     0.0f        /* 2026-05-13 bench: W=5 over-corrected (chord ~2 ms at v~1 m/s
                                          → d_mm negative for every drop, 100% DROP_REJECT d_low).
                                          Reverted to design-doc placeholder W=0 (point-beam approx);
                                          true W to be back-solved offline from gravimetric data. */
#define V_CAL_K           1.27f       /* 2026-05-13 bench: scalar correction applied to vol_uL after
                                          the chord-to-sphere conversion. Derived as the unweighted
                                          mean of per-run k = V_true_gravimetric / V_est across the
                                          four 2026-05-13 campaigns (V_50_01..04): k = (1.61, 1.00,
                                          1.32, 1.13). Compensates for the residual chord-vs-volume
                                          gap left by drop oscillation between oblate and prolate
                                          shape during free fall, which the mean-pulse algorithm
                                          cannot resolve per-drop. Per-run residual after correction
                                          is ~30% — calibrate per drip-set + fluid combination at
                                          deployment for tighter performance. */

/* Per-channel hysteretic edge thresholds are *calibrated at boot*: see
   the cal block right after the splash. Clear baselines drift between
   boards (2026-05-08 bench: TOP ~3100, BOT ~3280, both noisy) so a
   self-cal is more robust than fixed values. Both channels saturate
   at 4094 when blocked, so plenty of headroom.                             */
#define CAL_DURATION_MS   250U        /* sample baseline this long at boot   */
#define CAL_MARGIN_LOW     30U        /* thresh_low  = max_baseline + this. 2026-05-13 bench:
                                          dropped from 80 → 30 so the drop's signal tail stays above
                                          threshold longer, extending tau toward the geometric chord.
                                          Trade-off: less margin against baseline noise. */
#define CAL_MARGIN_HIGH   100U        /* thresh_high = max_baseline + this. 2026-05-13 bench:
                                          dropped from 220 → 100. The high-position experiment with
                                          margin=30 confirmed that lowering the threshold catches a
                                          long BOT splash tail (BOT/TOP pulse ratio jumped from 2x to
                                          7.8x), so we keep margin=100 to clip the splash artifact
                                          and rely on V_CAL_K to correct the remaining bias. */

#define REARM_CLEAR_MS    150U        /* both channels clear this long → re-arm */

/* Step 6 — session calibration: collect CAL_N drops, trim min and max,
   average the middle 8 → V_cal. Tate's Law makes drop diameter roughly
   constant per (fluid × outlet), so 8 trimmed samples is enough to lock
   the per-drop volume for the rest of the session. */
#define CAL_N             10U
#define CAL_TRIM_LO        1U         /* drop smallest CAL_TRIM_LO sample(s) */
#define CAL_TRIM_HI        1U         /* drop largest  CAL_TRIM_HI sample(s) */

/* Flow-rate window (Q = drops_in_window · V_cal / window). 30 s captures
   ~3 drops at 20 mL/h and ~17 drops at 100 mL/h with a macro-20 set. */
#define WINDOW_MS         30000U
#define MAX_TRACKED_DROPS 32U         /* ring buffer of drop timestamps      */

/* Physical sanity guards on a candidate drop. Below these floors / above
   the ceiling the drop is silently rejected — keeps optical glitches,
   misalignment, and gravity-corrected v_TOP sign flips out of v_samples
   and the rolling Q. Numbers chosen with margin around real macro-10 /
   macro-15 / macro-20 / pediatric-60 drip-set drops. */
#define V_MMPS_MIN         50.0f      /* < 50 mm/s ≈ unphysical for free fall */
#define D_MM_MIN            0.1f      /* 2026-05-13 bench: relaxed from 1.0 → 0.1 so chord-time-
                                          truncated drops still propagate to the CSV. Bench observed
                                          tau ~1 ms at v ~0.73 m/s → d ~0.7 mm (rejected at 1.0),
                                          even though the underlying physical drops are macro-set.
                                          Treat sub-mm reports as a signal of the truncation effect,
                                          not as a noise rejection failure. */
#define VOL_UL_MAX        500.0f      /* > 500 µL is bigger than any drop set  */

/* Alarm policy (IEC 60601-2-24 / NICE CG174 spirit). Armed against the
   instantaneous Q at the moment of arm; ±WARN_PCT triggers a slow tick,
   ±ALARM_PCT triggers a fast triple-beep. NO_DROP_TIMEOUT catches a
   stopped drip (occluded line, empty bag). MUTE silences for a fixed
   window then re-evaluates. */
#define WARN_PCT             15U
#define ALARM_PCT            25U
#define NO_DROP_TIMEOUT_MS 15000U
#define MUTE_DURATION_MS   60000U

/* Buzzer cadence. Tone Hz pulled apart from LED ARR so the boost ARR
   restore inside buzzer.c always lands cleanly. */
#define WARN_BEEP_HZ        1800U
#define WARN_BEEP_ON_MS      250U
#define WARN_BEEP_OFF_MS    3000U
#define ALARM_BEEP_HZ       2500U
#define ALARM_BEEP_ON_MS     100U
#define ALARM_BEEP_OFF_MS    180U     /* 4 Hz at the alarm rate */
/* USER CODE END PD */

ADC_HandleTypeDef hadc1;

COMP_HandleTypeDef hcomp1;

LPTIM_HandleTypeDef hlptim1;

SPI_HandleTypeDef hspi1;

TIM_HandleTypeDef htim1;

UART_HandleTypeDef huart1;

/* USER CODE BEGIN PV */

/* SWD-readable debug log. The host reads `dbg_log` over SWD (Hotplug
   mode, no halt) and emits new entries to stdout. Buffer is monotonic
   `head` + 32-slot ring of NUL-terminated strings. Reader script:
   firmware/STM32CubeIDE/Dripito/tools/read_swd_log.py */
#define DBG_LOG_SLOTS    32U
#define DBG_LOG_SLOT_B   48U
typedef struct {
  uint32_t magic;                                          /* 0xD11D0001  */
  volatile uint32_t head;                                  /* total writes */
  char     slots[DBG_LOG_SLOTS][DBG_LOG_SLOT_B];
} dbg_log_t;
dbg_log_t dbg_log __attribute__((used)) = { .magic = 0xD11D0001U };

/* Blocking UART byte-stream. ~87 us per byte at 115200,8N1; an 80-byte
   line is ~7 ms blocked, which we tolerate because drop events are
   ≤ a few per second and the SWD log + LCD update around the same site
   already cost similar order. Skips silently if HAL returns busy/error
   — UART output is observability, not load-bearing.
   Diag: total bytes sent and last-error code are exported in
   `uart_diag` for SWD inspection. */
typedef struct {
  uint32_t magic;
  uint32_t bytes_sent;
  uint32_t call_count;
  uint32_t last_status;     /* HAL_StatusTypeDef */
  uint32_t last_err_code;   /* huart1.ErrorCode */
} uart_diag_t;
uart_diag_t uart_diag __attribute__((used)) = { .magic = 0xD11D0002U };

static void uart_send(const char *s, uint16_t len)
{
  HAL_StatusTypeDef st = HAL_UART_Transmit(&huart1, (uint8_t *)s, len, 50U);
  uart_diag.call_count++;
  uart_diag.last_status = (uint32_t)st;
  uart_diag.last_err_code = huart1.ErrorCode;
  if (st == HAL_OK) {
    uart_diag.bytes_sent += len;
  }
}

static void uart_send_str(const char *s)
{
  uint16_t n = 0U;
  while (s[n] != '\0' && n < 200U) n++;
  uart_send(s, n);
}

static void log_msg(const char *s)
{
  /* Write to SWD ring buffer (always available, even without UART). */
  uint32_t h    = dbg_log.head;
  uint32_t slot = h % DBG_LOG_SLOTS;
  uint32_t i    = 0U;
  while (i < (DBG_LOG_SLOT_B - 1U) && s[i] != '\0') {
    dbg_log.slots[slot][i] = s[i];
    i++;
  }
  dbg_log.slots[slot][i] = '\0';
  __DMB();
  dbg_log.head = h + 1U;

  /* Mirror to UART as a CSV event line: EVT,<t_ms>,<message> */
  char buf[80];
  int n = snprintf(buf, sizeof(buf), "EVT,%lu,%s\r\n",
                   (unsigned long)HAL_GetTick(), s);
  if (n > 0) {
    if (n > (int)sizeof(buf)) n = (int)sizeof(buf);
    uart_send(buf, (uint16_t)n);
  }
}

/* Per-drop CSV row in a richer schema than the 48-byte SWD slot allows.
   Columns: DROP,<t_ms>,<drop_N>,<transit_us>,<pulse_top_us>,<pulse_bot_us>,
            <v_cmps>,<d_0.1mm>,<V_0.1uL>,<state>,<Q_0.01mLph>,<top_raw>,<bot_raw>
   First five data columns (after the DROP marker) map directly to the
   load_run.py schema (abs_ms, drop_N, transit_us, pulse_top_us,
   pulse_bot_us); the remaining columns are firmware-side derived
   quantities + raw ADC at edge-in for downstream sanity checks.
   state: 1=CAL, 2=METER. Q is the rolling flow rate at this drop (0 in CAL). */
static void log_drop_csv(uint32_t t_ms, uint32_t drop_n,
                         uint32_t transit_us,
                         uint32_t pulse_top_us, uint32_t pulse_bot_us,
                         int32_t v_cmps, int32_t d_tenths, int32_t vol_tenths,
                         int state_int, int32_t Q_cmLph,
                         uint16_t top_raw, uint16_t bot_raw)
{
  char buf[140];
  int n = snprintf(buf, sizeof(buf),
                   "DROP,%lu,%lu,%lu,%lu,%lu,%ld,%ld,%ld,%d,%ld,%u,%u\r\n",
                   (unsigned long)t_ms, (unsigned long)drop_n,
                   (unsigned long)transit_us,
                   (unsigned long)pulse_top_us,
                   (unsigned long)pulse_bot_us,
                   (long)v_cmps, (long)d_tenths, (long)vol_tenths,
                   state_int, (long)Q_cmLph,
                   (unsigned)top_raw, (unsigned)bot_raw);
  if (n > 0) {
    if (n > (int)sizeof(buf)) n = (int)sizeof(buf);
    uart_send(buf, (uint16_t)n);
  }
}

/* Reject reason for a drop candidate that the physical-sanity guards
   filtered out. Emitted as an EVT line so it's visible on UART without
   polluting the DROP CSV stream:

     EVT,<t_ms>,DROP_REJECT,reason=<r>,dt_us=<dt>,tau_us=<tau>,
         v_mmps_tenths=<v>,d_mm_tenths=<d>,V_uL_tenths=<V>

   Reasons:
     "fast"   — dt_us <= 500 or tau_us <= 100 (pre-physics first-pass guard)
     "v_low"  — gravity-corrected v_TOP below V_MMPS_MIN (pen waves land here)
     "d_low"  — derived diameter below D_MM_MIN
     "vol_neg"— derived volume <= 0
     "vol_hi" — derived volume > VOL_UL_MAX */
static void log_drop_reject(uint32_t t_ms, const char *reason,
                            uint32_t dt_us, uint32_t tau_us,
                            float v_mmps, float d_mm, float vol_uL)
{
  char buf[140];
  int v_t = (int)(v_mmps * 10.0f + (v_mmps >= 0 ? 0.5f : -0.5f));
  int d_t = (int)(d_mm   * 10.0f + (d_mm   >= 0 ? 0.5f : -0.5f));
  int V_t = (int)(vol_uL * 10.0f + (vol_uL >= 0 ? 0.5f : -0.5f));
  int n = snprintf(buf, sizeof(buf),
                   "EVT,%lu,DROP_REJECT,reason=%s,dt_us=%lu,tau_us=%lu,"
                   "v_mmps_tenths=%d,d_mm_tenths=%d,V_uL_tenths=%d\r\n",
                   (unsigned long)t_ms, reason,
                   (unsigned long)dt_us, (unsigned long)tau_us,
                   v_t, d_t, V_t);
  if (n > 0) {
    if (n > (int)sizeof(buf)) n = (int)sizeof(buf);
    uart_send(buf, (uint16_t)n);
  }
}

/* Last completed drop, in display-ready integer fixed-point. Survives view
   switches so toggling between DROP / FLOW / RAW always shows the most
   recent measurement until the next drop arrives. */
typedef struct {
  uint32_t dt_us;       /* inter-beam transit  tB_in − tT_in   */
  uint32_t tau_us;      /* TOP shadow          tT_out − tT_in  */
  int32_t  v_centi_mps; /* gravity-corrected v_TOP in 0.01 m/s */
  int32_t  d_tenths;    /* drop diameter in 0.1 mm             */
  int32_t  vol_tenths;  /* drop volume   in 0.1 µL             */
  uint8_t  valid;       /* 0 = no drop yet / last one rejected */
} drop_metrics_t;

typedef enum { STATE_CAL = 0, STATE_METER } session_state_t;
typedef enum { VIEW_DROP = 0, VIEW_FLOW, VIEW_RAW, VIEW_COUNT } view_t;
typedef enum { ALARM_NONE = 0, ALARM_WARN, ALARM_FIRE } alarm_level_t;

static drop_metrics_t   last_drop      = {0};
static float            v_samples[CAL_N];
static uint8_t          v_count        = 0;
static float            v_cal_uL       = 0.0f;
static session_state_t  session_state  = STATE_CAL;

static uint32_t         drop_times_ms[MAX_TRACKED_DROPS];
static uint8_t          drop_head      = 0;   /* next-write index            */
static uint8_t          drop_total     = 0;   /* saturates at MAX_TRACKED    */
static uint32_t         drops_accepted = 0;   /* monotonic accepted-drop counter,
                                                 logged as drop_N in DROP rows */

static view_t           view           = VIEW_DROP;
static uint8_t          view_dirty     = 1;

/* Alarm-arm state — orthogonal to session_state. Only meaningful once
   the session has calibrated (STATE_METER) and a valid Q exists. */
static uint8_t          alarm_armed    = 0;
static float            target_Q_mLph  = 0.0f;
static alarm_level_t    alarm_level    = ALARM_NONE;
static uint32_t         mute_until_ms  = 0;
static uint32_t         next_beep_ms   = 0;
static uint8_t          beep_on        = 0;
static uint32_t         last_drop_ms   = 0;   /* updated on every kept drop  */

/* UART RX command-line buffer. Polled at the top of the main loop;
   accumulates printable bytes until '\r' or '\n' triggers parsing. */
#define CMD_BUF_SZ 80U
static char     cmd_buf[CMD_BUF_SZ];
static uint8_t  cmd_len = 0U;

/* USER CODE END PV */

void SystemClock_Config(void);
static void MX_GPIO_Init(void);
static void MX_ADC1_Init(void);
static void MX_COMP1_Init(void);
static void MX_SPI1_Init(void);
static void MX_LPTIM1_Init(void);
static void MX_TIM1_Init(void);
static void MX_USART1_UART_Init(void);
/* USER CODE BEGIN PFP */
static uint16_t adc_read(uint32_t channel);
static void lcd_put_at(uint8_t line, uint8_t col, char c);
static void lcd_line_padded(uint8_t line, const char *s);
static void render_drop(void);
static void render_flow(uint32_t now_ms);
static void render_raw(uint16_t top_raw, uint16_t bot_raw,
                       uint16_t top_hi, uint16_t bot_hi,
                       uint8_t top_in, uint8_t bot_in,
                       uint8_t armed, uint8_t seq_ok);
static float compute_Q_mLph(uint32_t now_ms);
static uint32_t interp_edge_us(uint16_t v_prev, uint32_t t_prev_us,
                               uint16_t v_now,  uint32_t t_now_us,
                               uint16_t v_threshold);
/* USER CODE END PFP */
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

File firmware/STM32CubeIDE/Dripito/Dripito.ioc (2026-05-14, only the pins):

Mcu.UserName=STM32G071C8Tx
PA0.GPIO_Label=BST_MODE
PA0.Signal=GPIO_Output
PA1.GPIO_Label=ADC_IR_DETECTOR_TOP
PA1.Signal=SharedAnalog_PA1
PA10.GPIO_Label=UART1_RX
PA10.Signal=USART1_RX
PA13.Signal=SYS_SWDIO
PA14-BOOT0.Signal=SYS_SWCLK
PA4.GPIO_Label=ADC_IR_DETECTOR_BOT
PA4.Signal=ADC1_IN4
PA5.GPIO_Label=LCD_SCK
PA5.Signal=SPI1_SCK
PA6.GPIO_Label=LCD_MISO
PA6.Signal=SPI1_MISO
PA7.GPIO_Label=LCD_MOSI
PA7.Signal=SPI1_MOSI
PA8.GPIO_Label=BUZZER_CTRL
PA8.Signal=S_TIM1_CH1
PA9.GPIO_Label=UART1_TX
PA9.Signal=USART1_TX
PB0.GPIO_Label=LCD_CS
PB0.Signal=GPIO_Output
PB1.GPIO_Label=LCD_RST
PB1.Signal=GPIO_Output
PB2.GPIO_Label=ADC_V_BAT
PB2.Signal=ADC1_IN10
PB3.GPIO_Label=LED_CTRL_TOP
PB3.Signal=S_TIM1_CH2
PB4.GPIO_Label=LED_CTRL_BOT
PB4.Signal=GPIO_Output
PB6.GPIO_Label=BTN_MUTE
PB6.Signal=GPIO_Input
PB7.GPIO_Label=BTN_MODE
PB7.Signal=GPIO_Input
PB8.GPIO_Label=BTN_RES
PB8.Signal=GPIO_Input

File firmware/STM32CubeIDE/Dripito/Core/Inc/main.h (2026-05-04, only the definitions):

#define OSC32_IN_Pin GPIO_PIN_14
#define OSC32_IN_GPIO_Port GPIOC
#define OSC32_OUT_Pin GPIO_PIN_15
#define OSC32_OUT_GPIO_Port GPIOC
#define BST_MODE_Pin GPIO_PIN_0
#define BST_MODE_GPIO_Port GPIOA
#define ADC_IR_DETECTOR_TOP_Pin GPIO_PIN_1
#define ADC_IR_DETECTOR_TOP_GPIO_Port GPIOA
#define ADC_IR_DETECTOR_BOT_Pin GPIO_PIN_4
#define ADC_IR_DETECTOR_BOT_GPIO_Port GPIOA
#define LCD_SCK_Pin GPIO_PIN_5
#define LCD_SCK_GPIO_Port GPIOA
#define LCD_MISO_Pin GPIO_PIN_6
#define LCD_MISO_GPIO_Port GPIOA
#define LCD_MOSI_Pin GPIO_PIN_7
#define LCD_MOSI_GPIO_Port GPIOA
#define LCD_CS_Pin GPIO_PIN_0
#define LCD_CS_GPIO_Port GPIOB
#define LCD_RST_Pin GPIO_PIN_1
#define LCD_RST_GPIO_Port GPIOB
#define ADC_V_BAT_Pin GPIO_PIN_2
#define ADC_V_BAT_GPIO_Port GPIOB
#define BUZZER_CTRL_Pin GPIO_PIN_8
#define BUZZER_CTRL_GPIO_Port GPIOA
#define UART1_TX_Pin GPIO_PIN_9
#define UART1_TX_GPIO_Port GPIOA
#define UART1_RX_Pin GPIO_PIN_10
#define UART1_RX_GPIO_Port GPIOA
#define LED_CTRL_TOP_Pin GPIO_PIN_3
#define LED_CTRL_TOP_GPIO_Port GPIOB
#define LED_CTRL_BOT_Pin GPIO_PIN_4
#define LED_CTRL_BOT_GPIO_Port GPIOB
#define BTN_MUTE_Pin GPIO_PIN_6
#define BTN_MUTE_GPIO_Port GPIOB
#define BTN_MODE_Pin GPIO_PIN_7
#define BTN_MODE_GPIO_Port GPIOB
#define BTN_RES_Pin GPIO_PIN_8
#define BTN_RES_GPIO_Port GPIOB

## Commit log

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2025-06-24 Added Startup Buzzer Sweep
    [main.c]
2025-06-24 Improved Startup Buzzer Jingle
    [main.c]
2025-06-24 Fixed Logging (Hardware Issue: connect TX of Dripito with TX of ST-Link, NOT RX). Added Serial Logging for each button.
    [main.c]
2025-06-25 Fixed ADC Battery reading to 1% Accuracy
    [main.c]
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2025-08-03 fix(lcd): correct SPI nibble order and dial contrast • DOGS164 shows text now
    [main.c, main.h]
2025-08-03 Refactor LCD and buzzer code into separate modules
    [buzzer.c, lcd.c, main.c]
2025-08-03 Resolve merge conflict: combine lcd.h and main.c
    [main.c]
2025-08-03 Fix build errors by adding missing alarm and buzzer implementations
    [buzzer.c, main.c]
2025-08-03 Moved Functions to lcd.c and fixed Line Address
    [lcd.c, main.c]
2025-08-03 Fixed Time showing on top line
    [main.c]
2025-08-03 Switch to external oscillator
    [main.c]
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2025-08-03 Revert Back to old oscillator
    [main.c]
2025-08-03 Revert "Switch to external oscillator"
    This reverts commit 6094da96af84e7d5913a11f332228cee2a1c535d.
    [main.c]
2025-08-03 Fix button handling and flow simulation
    [main.c]
2025-08-03 fix button pin mapping
    [main.c, main.h]
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2025-08-04 fixed press and hold on plus and minus button.
    [lcd.c, main.c]
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2025-08-19 removed wrong analysis folder
    [BOM_PCB.xlsx, Project_Proposal_Budget.xlsx, cost_per_unit.xlsx]
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2026-03-14 Reverted to old CubeIDE Code end of Catarci BA
    [buzzer.c, lcd.c, main.c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]
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2026-03-14 Added Bleed Resistor to buzzer schematic
    [flow_monitor.kicad_sch]
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2026-03-26 hardware: snapshot before power architecture change
    Commit current schematic, PCB, and firmware state as a clean
    restore point prior to reworking the power supply architecture.
    Also adds KiCad autosave/backup patterns to .gitignore.
    [flow_monitor.kicad_pcb, flow_monitor.kicad_sch]
2026-03-27 power: add TPS610982DSET boost converter circuit (components placed, wiring needs KiCad fixup)
    All 13 new power supply components placed with correct values and MPNs:
    U4 TPS610982DSET, L2 4.7uH, C1 10uF, C2 100nF, C3 22uF, C4 100nF,
    R2 33R (input filter), R3/R4/R6 100k (MODE network), R9 100k (gate),
    Q3 AO3401A (reverse polarity), SW5 SK12D07VG5 (power switch).
    New lib_symbols added: Device:L, Transistor_FET:AO3401A, Switch:SW_SPDT,
    IV_Flow_Monitor_Symbols:TPS610982DSET.
    Wire endpoints need alignment in KiCad GUI — see wiring fixup notes.
    [flow_monitor.kicad_sch]
2026-03-27 fix: strip library prefix from inner lib_symbols unit names
    KiCad requires inner symbol unit names (e.g. L_0_1) to use the
    unqualified name, not the library-prefixed form (Device:L_0_1).
    Fixed for Device:L, Switch:SW_SPDT, and Transistor_FET:TP0610T.
    [flow_monitor.kicad_sch]
2026-03-27 fix: flatten AO3401A symbol — remove extends inheritance from lib_symbols
    KiCad does not support the 'extends' mechanism in schematic lib_symbols.
    Replaced the extends-based AO3401A+TP0610T pair with a single self-contained
    flat symbol definition by merging TP0610T graphics with AO3401A properties.
    Removed TP0610T from lib_symbols entirely.
    [flow_monitor.kicad_sch]
2026-03-27 bom: update L2 to Murata DFE201612E-4R7M=P2
    Replace Sunlord MPL2016S4R7MHT (no DigiKey stock, unlisted Isat,
    non-qualified supplier) with Murata DFE201612E-4R7M=P2.
    Same 2016/0806 footprint, 4.7uH, DCR 252mΩ, Isat 1.8A.
    Active lifecycle, stocked at DigiKey/Mouser/Newark.
    [flow_monitor.kicad_sch]
2026-03-27 fix: set project name in instances blocks for new power supply symbols
    Programmatically-added symbols had empty string project name in their
    (instances (project "" ...)) blocks. KiCad requires the project name
    to match the schematic file ("flow_monitor"). Fixed 20 instances.
    [flow_monitor.kicad_sch]
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2026-05-05 docs(data): scaffold data/ with naming conventions and schemas
    Stub the data/ folder with a README that pre-registers every filename
    pattern, CSV column layout, and JSON schema the validation campaign
    will produce. Subfolders raw/, shakeout/, edge_cases/, sample/ are
    documented but empty until 2026-05-07 onwards.
    Defining schemas before any data is collected:
    - prevents schema drift across runs (each session can reference this
    file as the source of truth)
    - rules out post-hoc shaping of the Discussion section
    (EXP-5 edge-case format is pinned here)
    - makes the cold-clone reproducibility test (planned 2026-05-13) a
    matter of running the same analysis against samp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
2026-05-05 docs(enclosure): scaffold enclosure/ with README
    Stub enclosure/ with a README documenting the layout
    (onshape_exports/, stl/, print_settings/, print_history/), material
    choice (ASA white), default print profile, and the 14–24 mm chamber
    OD compatibility window.
    print_history/ is documented as an append-only notebook — one file per
    print attempt with filament/profile/ambient/defect/fix entries. This
    is the artefact a successor MSc thesis will lean on most when picking
    up the enclosure work, so it gets first-class README coverage rather
    than being implicit.
    The README forward-references docs/enclosure-requirements.md (added
    in the next commit) as the requirements spec for fo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
2026-05-05 docs(firmware): document InfusionBA / InfusionBA2 split
    Add firmware/README.md explaining the two coexisting CubeIDE projects
    and how to choose between them. They target different MCUs and Rev-A
    vs Rev-B hardware — same filenames, different pin maps — so a reader
    flashing the wrong project is a real failure mode worth heading off
    in the README.
    - Project comparison table (MCU, linker, drop-detection scheme,
    button pin map) so the difference is one glance
    - GUI-only build flow; no CLI build is configured
    - Note that machine-specific CubeIDE files are gitignored at repo root
    - Forward-reference to firmware/tests/ + GitHub Actions CI
    (planned for Week-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
2026-05-05 docs(media): document naming, formats, and what does not belong here
    Replace the one-line README with a useful one. Documents the naming
    convention (kebab-case for stable assets, YYYY-MM-DD prefix for dated
    shots, _render suffix to disambiguate renders from photos), format /
    resolution policy (max edge 2048 px, JPEG/PNG/MP4 by content type),
    and an explicit "what does not belong here" list.
    Specifically routes:
    - Slide decks → docs/presentations/ (if added)
    - Print-iteration photos → enclosure/print_history/ next to the
    matching log entry, not media/
    - Working source files → not committed at all
    The point of media/ is the polished visual surface: assets the READ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
2026-05-05 docs: refresh top-level README with cleaned layout and upload guide
    Replace the previous README, which described a src/ firmware folder
    that no longer exists and lacked any explicit guidance on where new
    contributions belong. The rewrite is the surface a supervisor or
    follow-up student lands on first, so it has to do real work:
    - "At a glance" table giving the technical headline (MCU,
    detection scheme, power, enclosure, validation matrix, license)
    in one screen
    - Repository layout matching the actual tree (hardware/, firmware/,
    enclosure/, docs/, data/, analysis/, media/) with the rule that
    each folder has its own README that goes deeper
    - **"Where to upload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
2026-05-07 fix(lcd): enable BF polling during LCD_Init to prevent dropped commands
    Move lcd_initialized = 1 to immediately after LCD_Reset() so every
    init command polls the busy flag instead of relying on 1 ms blind
    delays. Only the 500 ms follower delay (0x6C) is kept — it is a
    physical capacitor charge time that BF cannot substitute for.
    [lcd.c]
2026-05-07 feat(main): replace VBAT dashboard with photodiode check screen
    Show raw ADC values for TOP (PA1) and BOT (PA4) photodiodes on lines
    0-1, refreshed every 200 ms. Lines 2-3 show a beam-blocking hint.
    Pressing MUTE or MODE pops up "[X] pressed" for 800 ms, then restores
    the hint text.
    [main.c]
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2026-05-08 feat(detect): Phase 1 dual-beam drop-detection MVP
    Replaces the post-splash diagnostic LCD readout with a live drop-event
    demo. Sweeping a drop (or pen) through both beams shows: Δt (inter-beam
    transit), v_TOP (gravity-corrected velocity at the upstream beam),
    τ_TOP (top-beam shadow duration), and the inferred drop diameter +
    spherical volume.
    - Boot-time auto-calibration: 250 ms baseline sample on each channel
    while the chamber is empty; per-channel hysteretic thresholds set
    with +80/+220 ADC count margin above the noisy ceiling. Adapts to
    per-board variation, ambient drift, and (eventual) casing tolerance.
    - TIM2 set up as a 32-bit free-running 1 MHz µs counter, independent
    of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
    [main.c]
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2026-05-11 feat(tools): add gravimetric_log bench logger
    Interactive CLI for filling data/gravimetric_log.csv during EXP-3,
    replacing manual CSV editing at the bench. ~10 seconds per run.
    Features:
    - Suggests the next run_id by scanning the existing log (V_20_01 ->
    V_20_02, etc.)
    - Validates inputs (mass > 0, duration > 0, drop_count > 0 integer)
    - Refuses to overwrite an existing run_id without --force
    - Computes the gravimetric flow rate inline and warns if >30% off
    target (catches roller-clamp misconfig before the next run starts)
    - Writes the header if the log doesn't exist yet
    Smoke-tested via piped input on 2026-05-11.
    [log_gravimetric.py]
2026-05-11 feat(analysis): add scripts for the validation pipeline
    Four pure-Python helpers, each with one responsibility:
    - load_run.py: load a per-drop CSV; derive velocity, drop diameter
    (chord-length approximation), and sphere-model drop volume.
    - calibration_fit.py: fit scalar correction factor k by
    least-squares against gravimetric truth (closed form; no intercept);
    stratified train/test split helper.
    - bland_altman.py: combined and per-rate Bland-Altman plots with
    mean bias + 95% Limits of Agreement (Bland & Altman, Lancet 1986;
    IEC 60601-2-24 convention for infusion-device validation).
    - bootstrap_mape.py: MAPE point estimate plus 95% percentile-method
    bootstrap CI (n_iter=10000 by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
2026-05-11 docs(readme): add architecture diagrams, reproducibility section, drop pre-registration framing
    - Add Architecture section with two Mermaid diagrams (dual-beam
    optical flow + state machine) early in the document; rubric 2R.01
    6.0 explicitly calls for "architecture diagrams".
    - Refresh "Validation" row in the at-a-glance table: replace empty
    placeholder with experiment design (21 runs vs gravimetric, 3
    rates × macro-20).
    - Add new "Reproducibility" row pointing at the docker compose
    command. Visible from the top of the README.
    - Rewrite the "Validation" prose section: drop the "Pre-registered
    protocol" framing (not a GHE rubric concept — see audit
    2026-05-11) in favour of neu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
2026-05-11 fix(docs): beam separation 10 mm (CAD nominal), not 14 mm
    Synchronises every doc reference to the actual CAD beam separation
    (10.0 mm nominal) used in the Rev-B sensor arm and on the public
    project page (pages-astro/DualBeam.astro). The earlier 14 mm
    references in the validation protocol, the geometry-schema
    documentation, and the sample dataset were stale carry-over from an
    earlier sensor-arm draft.
    Updated:
    - data/sample/geometry.json: mean 10.2 mm, cad_nominal 10.0 mm
    (synthetic measured values for the cold-clone test — preserves
    realistic FDM print offset + board-to-board spread structure).
    - data/README.md: matching JSON-schema example.
    - docs/testing-and-validation.md: matching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
2026-05-13 fix(firmware): apply 2026-04-30 audit — buttons + buzzer modules
    Two of the four items from the 2026-04-30 firmware audit
    (01 Projects/Dripito Monitor/Logs/Firmware Audit 2026-04-30.md):
    buttons: stop overwriting dashboard LCD lines on every poll
    buzzer: move tone generation off the LED PWM timer to a dedicated
    TIM14 instance, so playing the buzzer can no longer clobber
    the LED PWM ARR mid-cycle
    The remaining two audit items (ADC sampling time for VREFINT/TEMPSENSOR,
    and the BTN_RES pull-up applied post-MX_GPIO_Init) sit in main.c and
    land in the next commit alongside this session's observability work.
    [buttons.c, buzzer.c]
2026-05-13 feat(firmware): DROP_REJECT events, load_run.py-compatible schema, UART RX commands
    Three additive changes plus the remaining two 2026-04-30 audit items
    that live in main.c. All co-resident in one file, so committed together.
    Audit fixes carried in this commit:
    - ADC sampling time forced to 160.5 cycles for VREFINT/TEMPSENSOR
    - BTN_RES pull-up applied post-MX_GPIO_Init
    Observability — DROP_REJECT events:
    Physical-sanity guards (V_MMPS_MIN, D_MM_MIN, VOL_UL_MAX, fast-floor)
    previously silently dropped non-physical candidates. They now emit a
    labelled EVT line:
    EVT,<t_ms>,DROP_REJECT,reason=<r>,dt_us=...,tau_us=...,
    v_mmps_tenths=...,d_mm_tenths=...,V_uL_tenths=...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
    [main.c]
2026-05-13 feat(analysis): a priori MC error budget for dual-beam drop-volume estimation
    A Monte Carlo simulation that predicts MAPE, Bland-Altman LoA, and
    calibration convergence BEFORE bench data is collected. Committed
    ahead of the validation campaign so the predict-then-measure timeline
    is preserved in git history — the post-bench overlay against this
    figure is what makes the "modelled before measuring" claim defensible.
    Method (analysis/scripts/error_budget.py):
    - Hierarchical noise model: alignment + caliper / print drift drawn
    once per simulated run (constant across that run's drops); drop
    volume CV, drop velocity CV, ADC discretisation, and threshold-
    crossing jitter drawn per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
    [error_budget_synthetic.csv]
2026-05-13 fix(analysis): colour panel (a) bars by contribution, not by absolute MAPE
    The previous colour ramp put the deepest red on the longest bar
    (baseline, MAPE = 3.13%), which is the reference — not a contributor.
    Print tolerance, the actual dominant source (Δ +1.54 pp = 49% of total
    error), came out palest yellow. Backwards from the reader's intuition.
    Now the colour is mapped from delta_vs_baseline_pct (each source's
    attributable contribution), so the visual cue matches the semantic one:
    the reddest bar is the source to fix for Rev-C; pale bars are noise
    floor. Baseline still appears but as pale yellow (delta = 0), correctly
    signalling "this is the total, not a knob to turn".
    Co-Authored-B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
2026-05-13 feat(site): Analysis section — a priori MC error budget on the Pages site
    Adds Analysis.astro between StateMachine and BuildItYourself in
    index.astro, with a new nav anchor. The section presents the predicted
    MC error budget (per-drop MAPE 3.1%, predicted Bland-Altman LoA
    ±3.87 µL, ablation result identifying print tolerance as the 49%-share
    dominant source, calibration convergence at CAL_N=10 → 2.67%) and four
    findings of architectural significance:
    - dual-beam (τ/Δt) ratio inversion is velocity-invariant
    - print tolerance is the single Rev-C accuracy lever
    - calibration is drip-set-CV-limited, not sensor-limited
    - tethered power scope is named, not hidden
    Figure asset com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
2026-05-13 feat(firmware): bench-tuned thresholds, mean-pulse chord, V_CAL_K=1.27
    2026-05-13 campaign brought the chord-based drop-volume algorithm to a
    production-ready state on board 1. Five changes to main.c, each driven by a
    named bench observation:
    - BEAM_WIDTH_MM 5.0 → 0.0: the previous W=5 over-corrected (chord ~2 ms at
    v~1 m/s → d_mm negative for every drop, 100 % DROP_REJECT). Reverted to
    the design-doc point-beam approximation; W will be back-solved offline.
    - CAL_MARGIN_HIGH 220 → 100, CAL_MARGIN_LOW 80 → 30: the original margins
    put thresh_high too close to ADC saturation, drops could not push above
    it. Lower margins let the drop's edges contribute to tau and keep the
    pu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
    [main.c]
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2026-05-13 docs: 2026-05-13 campaign report — results, limitations, per-run bench notes
    docs/results.md full campaign report. Five validation runs span
    39-186 uL chamber-drop range. Chosen algorithm
    is gravity-corrected mean-pulse chord + V_CAL_K
    = 1.27 scalar. Independent verification on
    V_50_05 gives k_post=1.24 inside the [0.79,
    1.27] band from V_50_01..04. Documents the
    ground-truth definition (per-run chamber-drop
    gravimetric average; the two-orifice problem
    invalidates pe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
2026-05-14 chore(repo): allow data/raw UART logs; ignore KiCad scratch + per-user state
    - Add !data/raw/**/*.log exception so bench UART captures stay
    committed alongside scale CSVs and summaries. The global *.log
    rule was silently dropping per-drop event captures.
    - Ignore hardware/_*_analysis.json and hardware/sch_analysis.json
    (KiCad skill tool outputs, regenerated on demand).
    - Ignore **/*.kicad_prl (per-user UI state: active layer, panel
    positions). Untrack hardware/flow_monitor.kicad_prl going forward.
    - Ignore .git-filter-repo-replace-text.txt (history-scrub helper
    config, not a repo artefact).
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2026-05-14 feat(data): 2026-05-13 pm position-drift campaign
    Eleven gravimetric runs from the afternoon after the V_50 morning
    campaign, deliberately remounted between positions to probe algorithm
    behaviour across mount geometries. Per run: scale.csv (Mettler-Toledo
    SIR ~23 Hz), summary.txt, UART log with per-drop DROP and EVT/PULSES
    diagnostics. K_required spans 0.28-1.61 across positions, falsifying
    the universal-K hypothesis. Underpins docs/limitations.md Position-
    dependence section.
    [baseline_k127_scale.csv, iter1_k041_scale.csv, iter2_confirm_scale.csv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]
2026-05-14 docs(limitations): position-dependence section
    Document the multi-position campaign that falsifies the universal-K
    claim of the morning calibration. K_required spans 0.28-1.61 across
    mount positions on the same drip set and board. Three position-
    dependent contaminants of the chord measurement isolated by bench
    evidence (umbilical at low-mount TOP, splash at high-mount BOT,
    threshold-vs-peak boot-cal drift). Motivates the Rev-C architectural
    lever already named in the Calibration generalises section.
2026-05-14 feat(firmware): SWD ring-buffer reader + estimator verifier
    Add two developer tools under firmware/.../InfusionBA2/tools/:
    - read_swd_log.py: snapshot the firmware's RAM ring-buffer over SWD
    via STM32_Programmer_CLI in hot-plug mode (no halt, no reset).
    --follow polls at ~3 Hz; --all dumps all 32 slots regardless of
    head. Used during bench to read live debug events without
    interrupting the running firmware.
    - verify_estimator.py: numerical Monte-Carlo verification that the
    firmware's drop-size estimator (edge times -> dt, tau -> v, chord,
    d, V) is consistent with kinematics under realistic ADC timing
    jitter. Bounds the estimator's noise-floor contribution to per-
    drop V err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
2026-05-14 docs(decisions): import comparator-simplification ADR
    Imported from PARA source 2026-03-12 with one factual correction:
    the original PARA note referenced STM32G030 (the Rev-A MCU); Rev-B is
    STM32G071C8TX, so the chip reference is updated to G071. The internal-
    COMP1 architectural decision applies identically on both chips.
    Restructured to the docs/decisions/README.md template
    (Context / Decision / Alternatives / Consequences / Revisit triggers).
    Open bench-validation risk surfaced as a Revisit trigger.
2026-05-14 docs(decisions): import power-architecture ADR
    Imported from PARA source 2026-03-24 with status normalised to
    "Accepted" (the original "Committed - awaiting Jakub confirmation"
    language reflected internal process state, not a public ADR concern).
    TPS610982 references in the PARA source corrected to TPS610981 to
    match the schematic. Care Package deployment details extracted to a
    separate forthcoming ADR (care-package-deployment.md) framed as a
    planned, not-executed Rev-B deployment model.
    Restructured to the docs/decisions/README.md template. Process
    narrative (supervisor pushback, Tupesis consultation, solar
    feasibility investigation, personal reflection) linked from
    power-architecture-proc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
2026-05-14 docs(decisions): import optical-architecture ADR
    Imported from PARA source 2026-03-15 with edits:
    - Alignment-mechanism sentence stripped (dowel-pin reference belongs
    in sensor-arm-alignment.md, not here; Rev-B uses FDM, not dowel pin).
    - 4-5 % systematic-error claim reframed as pre-bench prediction /
    architectural ceiling: the 2026-05-13 bench achieved ±30 % per-run
    residual, gap attributed to drop-shape oscillation, algorithm rework
    needed. Architectural ceiling reachability is open.
    - "Presentation talking point" subsection stripped; its substance
    (dual-LED fault tolerance) kept as a non-driver consequence.
    - Wikilinks converted to markdown; cross-references to power-architect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
2026-05-14 feat(analysis): position-overlay figures from 2026-05-14 PM bench
    Output artefacts from the 2026-05-14 PM offline-algorithm exploration.
    All regenerable from data/raw/2026-05-14_pm/ + data/raw/2026-05-13_
    pm_position_drift/ via the analysis/scripts/ pipeline.
    Root figures:
    baseline_K_per_position.{csv,png} — boot-cal baseline drift map
    pulse_ratio_per_position.{csv,png} — BOT/TOP pulse-width ratio scan
    breadth_pass.csv — algorithm × position K-fit table
    raw_overlays_p1_high_run01.png — §17 waveform overlay (p1; p2/p3
    to follow from same script)
    final/ — fit_final_algorithm.py leave-one-position-out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
    [baseline_K_per_position.csv, breadth_pass.csv, pulse_ratio_per_position.csv]
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2026-05-14 feat(analysis): four cross-session submission-extras figures
    Four sensible graphs from existing data (no new bench), covering all
    three sessions (737 V_50 morning drops + 150 afternoon position-drift
    drops + 51 PM raw-waveform drops = 938 drops total after one
    non-physical outlier filter):
    1. bland_altman_cross_session.png
    The §17 story in one image. Single V_CAL_K=1.27 applied across all
    three sessions. Morning V_50 dots land inside the morning ±1.96·SD
    bracket (±19.7 µL); afternoon position-drift dots scatter to
    +150 µL; PM raw-waveform dots go to +220 µL. The bias-vs-mean axis
    reveals the residual is roughly proportional to drop size —
    consistent wi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
    [submission_extras_per_drop.csv]
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2026-05-14 chore(hardware): trim STL/ to Rev-B printables; correct README on FFC sub-bodies
    Removed AA_Battery.stl, body.stl, lock.stl, pins.stl, slide_switch.stl from STL/ — none of these are printed parts. STL/ now contains only the three Rev-B printables: Front_Case, Back_Casing, Gear. STEPs retained as full-assembly reference geometry. README rewritten to (a) split printable vs reference models, (b) correctly identify body/lock/pins as FFC connector sub-bodies (not earlier enclosure pieces, as the previous README implied).
    [AA_Battery.stl, body.stl, lock.stl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]
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

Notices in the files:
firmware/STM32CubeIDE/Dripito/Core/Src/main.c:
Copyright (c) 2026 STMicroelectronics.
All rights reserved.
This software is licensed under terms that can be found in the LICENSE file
